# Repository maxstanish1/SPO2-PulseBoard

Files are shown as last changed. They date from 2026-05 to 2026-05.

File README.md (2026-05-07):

# SPO2-PulseBoard
A custom heart rate and SpO2 monitor built on an Arduino Uno R3 with a MAX30105 sensor and SSD1306 OLED display. Features a custom PCB, mode-switching buttons, and an alarm LED. Uses lightweight R-ratio SpO2 calculation and peak-detection heart rate — all tuned to run within the Arduino Uno's RAM limits.



# PulseBoard

A custom heart rate and SpO2 monitor built on an Arduino Uno R3 with a MAX30105 sensor and SSD1306 OLED display. Features a custom PCB, mode-switching buttons, and an alarm LED. Uses lightweight R-ratio SpO2 calculation and peak-detection heart rate — all tuned to run within the Arduino Uno's RAM limits.

---

## Hardware

| Component | Details |
|---|---|
| Microcontroller | Arduino Uno R3 |
| Sensor | MAX30105 optical heart rate / SpO2 |
| Display | SSD1306 128×32 OLED (I2C) |
| PCB | Custom — see `/hardware` for Gerber files |

### Pin Map

| Pin | Function |
|-----|---|
| D2 | Menu button — cycles between Heart Rate and SpO2 mode |
| D3 | Up button — reserved for future use |
| D4 | Down button — reserved for future use |
| D12 | Alarm LED — flashes when no finger is on the sensor |
| SDA / SCL | Shared I2C bus → MAX30105 + SSD1306 |

### Button Circuit
All three buttons are active-low, held HIGH by 1kΩ pull-up resistors (R1, R2, R3) with 100nF decoupling capacitors for hardware debounce. The alarm LED is driven through a 1kΩ current-limiting resistor (R4).

---

## Features

- **Heart Rate (BPM)** — peak detection on a rolling IR signal window with a 4-beat rolling average
- **SpO2 (%)** — R-ratio method with a quadratic calibration formula for accurate readings in the healthy range
- **Mode switching** — press D2 to toggle between Heart Rate and SpO2 mode; a splash screen confirms the switch
- **Alarm LED** — flashes at 1Hz on D12 when no finger is detected, turns off immediately when a finger is placed
- **Stable display** — 500ms refresh throttle prevents flicker; readings are held back for the first few seconds until the signal stabilizes

---

## How It Works

### Finger Detection
The sketch polls the MAX30105 every loop. An IR value above 50,000 indicates a finger is present (tissue absorbs the light). Below that threshold, the sensor is reading open air. All HR and SpO2 state resets on each new finger placement.

### Heart Rate Detection
A 10-sample rolling window tracks the IR signal's min, max, and range. Beat detection fires when the signal crosses 50% of the range, subject to these parameters:

| Parameter | Value |
|---|---|
| Threshold | 50% of signal range |
| Minimum signal range | 400 |
| Minimum time between beats | 400ms |
| First beat | Always skipped (timing invalid) |
| Valid BPM range | 50 – 120 |
| Rolling average | 4 beats |
| Avg display delay | 8 seconds |

### SpO2 Calculation
AC (peak-to-peak) and DC (midpoint) values are computed for both the Red and IR channels from the same 10-sample window. The R-ratio is calculated as:

```
R = (redAC / redDC) / (irAC / irDC)
```

R is then passed through a quadratic calibration formula fitted to empirical blood oxygen absorption data:

```
SpO2 = -45.060 × R² + 30.354 × R + 94.845
```

The result is clamped between 70–100% and smoothed with a 9-reading rolling average. Readings are displayed after 5 seconds.

> **Note:** This formula is accurate in the healthy range (95–100%). Readings below ~90% should be treated as approximate — the sensor is not designed for clinical low-SpO2 accuracy.

---

## Libraries Required

Install these through the Arduino IDE Library Manager before compiling:

- [Adafruit SSD1306](https://github.com/adafruit/Adafruit_SSD1306)
- [Adafruit GFX](https://github.com/adafruit/Adafruit-GFX-Library)
- [SparkFun MAX3010x](https://github.com/sparkfun/SparkFun_MAX3010x_Sensor_Library) — provides `MAX30105.h`

> **Note:** This project does NOT use `spo2_algorithm.h`. That library was tested but exceeded the Uno's available RAM. SpO2 logic here is a custom lightweight implementation.

---

## Usage

1. Wire up the hardware according to the pin map above or use the custom PCB
2. Install the required libraries
3. Upload `heart_monitor.ino` to your Arduino Uno R3
4. Place your finger **lightly** on the sensor — pressing too hard flattens the pulse waveform and stops beat detection
5. Press **D2** to switch between Heart Rate and SpO2 mode
6. Wait 8 seconds for a stable heart rate average, or 5 seconds for an SpO2 reading

---

## Known Limitations

- **Finger pressure is critical** — too much pressure drops the signal range below 400 and halts detection
- **INT pin unused** — the MAX30105 interrupt pin is wired on the PCB but unconnected in firmware. Currently the sketch polls the sensor every loop. Future enhancement: wire INT to D7 for event-driven reads
- **SpO2 accuracy** — reliable in the 95–100% range; not suitable for clinical use
- **BPM range** — capped at 50–120 BPM; athletes with resting HR below 50 will see no reading

---

## Project Structure

```
PulseBoard/
├── firmware/
│   └── heart_monitor.ino
├── hardware/
│   └── (Gerber files, schematic)
└── README.md
```

---

## License

MIT

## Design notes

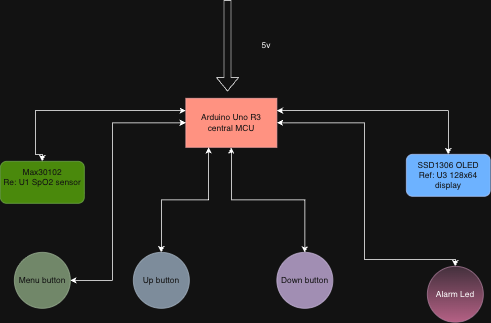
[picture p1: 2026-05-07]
Untitled Diagram.drawio (1).png

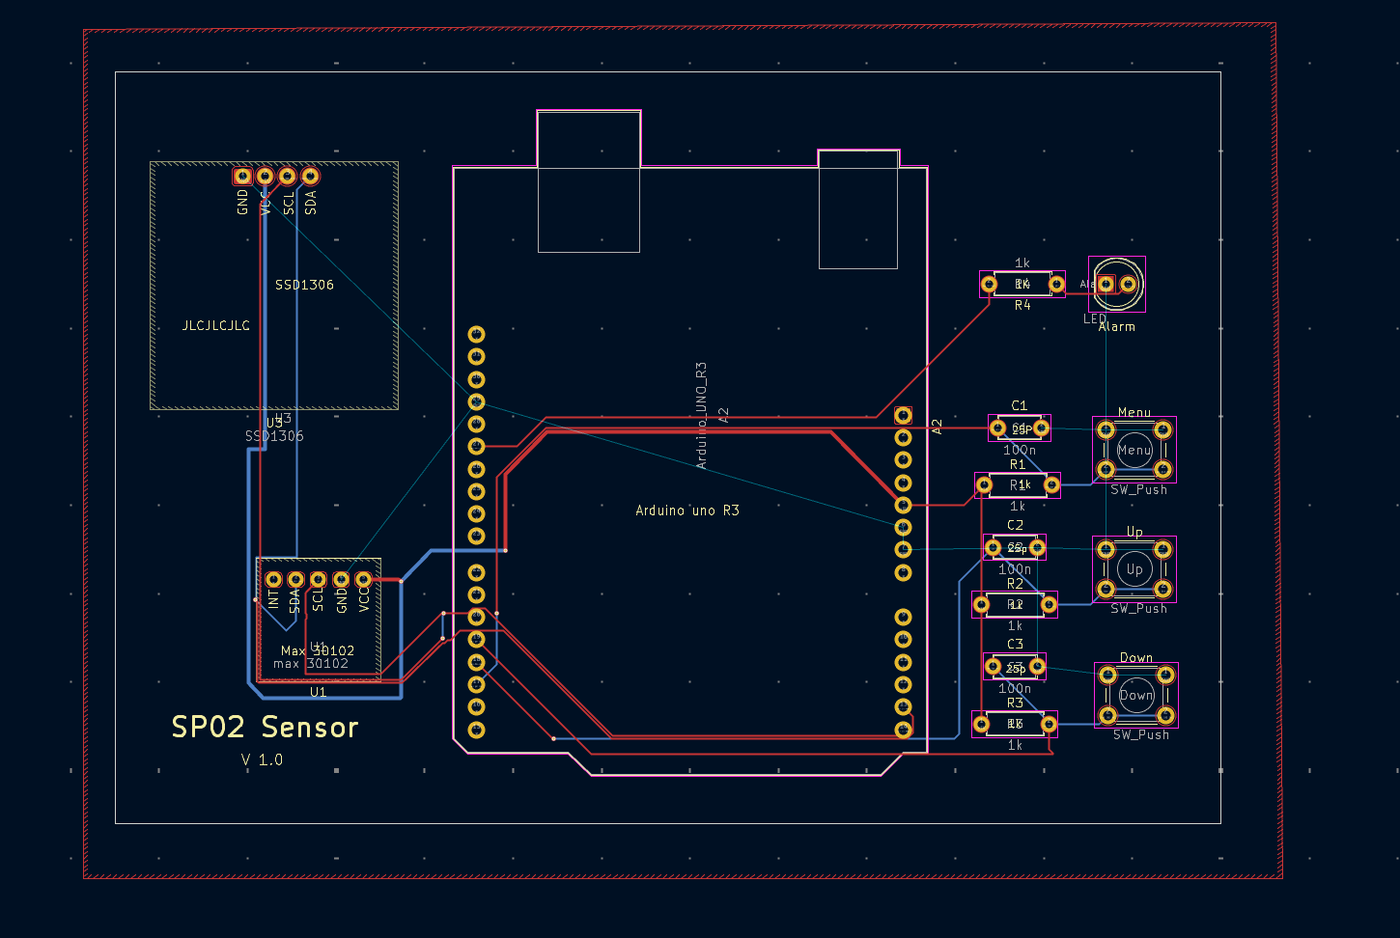
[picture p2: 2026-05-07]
SPO2 KiCAD layout.png

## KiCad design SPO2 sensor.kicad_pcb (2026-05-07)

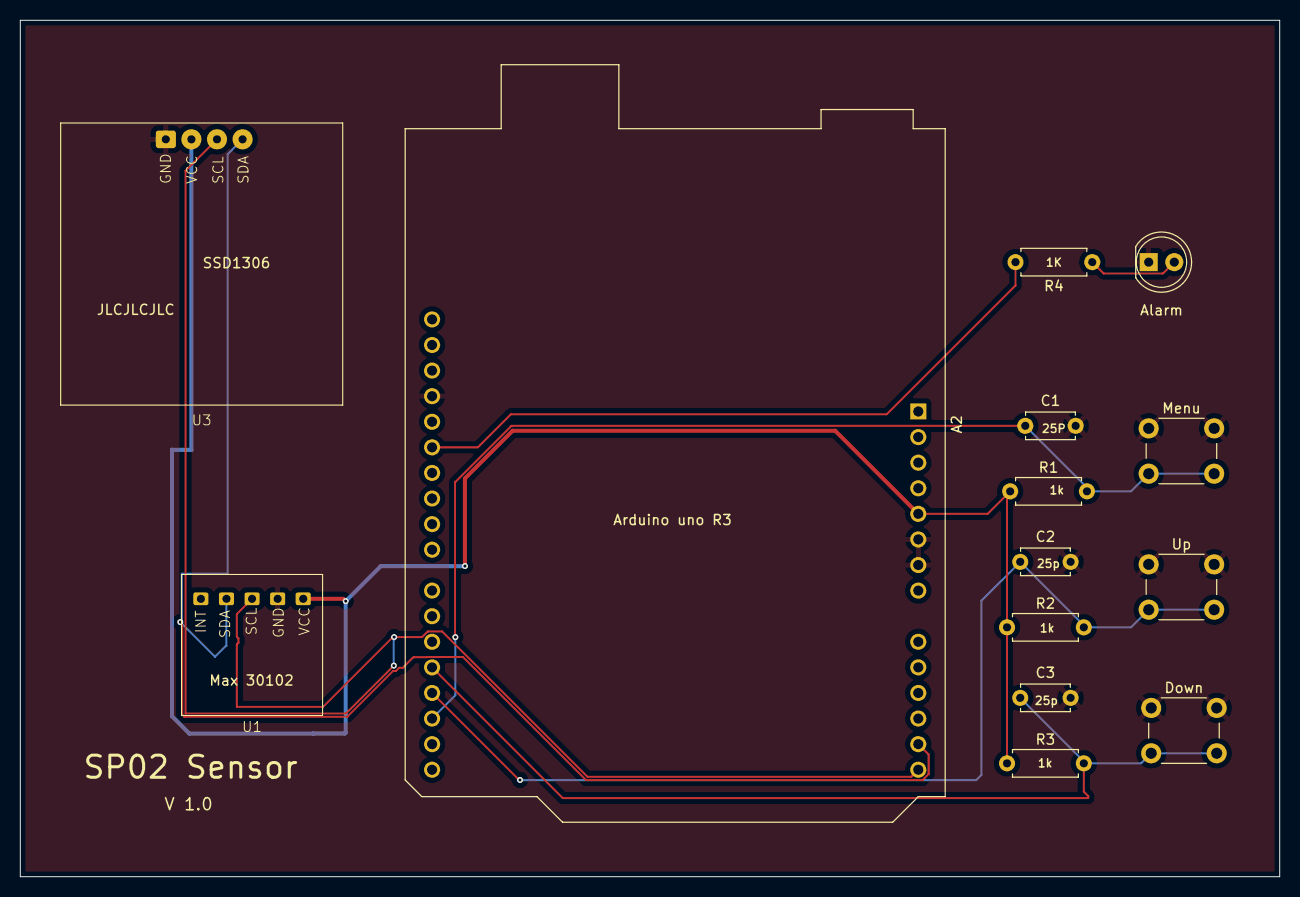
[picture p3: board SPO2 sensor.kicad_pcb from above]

Board: 2 copper layers, 125.0 x 85.0 mm, 14 parts (0 on the bottom side), 9 nets.

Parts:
A2: Arduino_UNO_R3
Alarm: LED; LED_D5.0mm
C1, C2, C3: 100n; C_Disc_D4.7mm_W2.5mm_P5.00mm
Down: SW_Push; SW_PUSH_6mm
Menu: SW_Push; SW_PUSH_6mm
R1, R2, R3, R4: 1k; R_Axial_DIN0207_L6.3mm_D2.5mm_P7.62mm_Horizontal
U1: max 30102; spo2 max30102
U3: SSD1306
Up: SW_Push; SW_PUSH_6mm

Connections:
+5V: A2.5 (+5V), R1.1, R2.1, R3.1, U1.5 (VCC), U3.2 (SCL)
GND: A2.6 (GND), A2.7 (GND), A2.29 (GND), Alarm.1 (K), C1.2, C2.2, C3.2, Down.1, Menu.1, U1.4 (GND), U3.1 (Vcc), Up.1
unnamed: A2.17 (D2), C1.1, Menu.2, R1.2
unnamed: A2.18 (D3), C2.1, R2.2, Up.2
unnamed: A2.19 (D4), C3.1, Down.2, R3.2
unnamed: A2.27 (D12), R4.2
unnamed: Alarm.2 (A), R4.1
unnamed: A2.14 (SCL/A5), U1.3 (SCL), U3.3 (SDA)
unnamed: A2.13 (SDA/A4), U1.2 (SDA), U3.4 (GND)

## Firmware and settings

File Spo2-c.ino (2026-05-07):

/*
 * Heart Rate & SpO2 Monitor
 * Hardware: Elegoo Uno R3 + MAX30105 + SSD1306 OLED
 * 
 * Pin assignments (from PCB schematic):
 *   D2  → Menu button  (cycles between HR and SpO2 mode)
 *   D3  → Up button    (reserved / future use)
 *   D4  → Down button  (reserved / future use)
 *   D12 → Alarm LED    (flashes when no finger on sensor)
 *   SDA/SCL → MAX30105 + SSD1306 on I2C bus
 *
 * Modes:
 *   MODE 0 = Heart Rate (BPM)
 *   MODE 1 = Blood Oxygen (SpO2 %)
 *
 * Button D2 cycles between modes.
 * LED on D12 flashes at 1Hz when no finger is detected, stays OFF when finger is on.
 */

#include <Wire.h>
#include <Adafruit_GFX.h>
#include <Adafruit_SSD1306.h>
#include "MAX30105.h"

// ─── Display ──────────────────────────────────────────────────────────────────
#define SCREEN_WIDTH    128
#define SCREEN_HEIGHT    32
#define OLED_RESET       -1
#define SCREEN_ADDRESS 0x3C
Adafruit_SSD1306 display(SCREEN_WIDTH, SCREEN_HEIGHT, &Wire, OLED_RESET);

// ─── Sensor ───────────────────────────────────────────────────────────────────
MAX30105 particleSensor;

// ─── Pin definitions (from Gerber schematic) ──────────────────────────────────
#define PIN_BTN_MENU  2    // Menu button  → cycles mode
#define PIN_BTN_UP    3    // Up button    → reserved
#define PIN_BTN_DOWN  4    // Down button  → reserved
#define PIN_ALARM_LED 12   // Alarm LED    → flashes when no finger

// ─── Mode ─────────────────────────────────────────────────────────────────────
#define MODE_HR   0
#define MODE_SPO2 1
int currentMode = MODE_HR;

// ─── Button debounce ──────────────────────────────────────────────────────────
bool     lastMenuState     = HIGH;
unsigned long lastMenuTime = 0;
#define DEBOUNCE_MS 50

// ─── LED flash state ──────────────────────────────────────────────────────────
unsigned long lastLedToggle = 0;
bool          ledState       = false;
#define LED_FLASH_INTERVAL 500

// ─── Heart rate detection ─────────────────────────────────────────────────────
const byte RATE_SIZE = 4;
byte       rates[RATE_SIZE];
byte       rateSpot        = 0;
long       lastBeat        = 0;
float      beatsPerMinute  = 0;
int        beatAvg         = 0;
int        displayBPM      = 0;
bool       beatDetected    = false;
bool       firstBeatSkipped = false;

// ─── IR signal buffers ────────────────────────────────────────────────────────
long irValueBuffer[10];
byte bufferIndex = 0;
long irMin = 999999;
long irMax = 0;

// ─── SpO2 calculation buffers ─────────────────────────────────────────────────
const byte SPO2_BUF_SIZE = 9;
long  redBuffer[10];
long  irBuffer_spo2[10];
byte  spo2BufIndex   = 0;
int   displaySpO2    = 0;
float spo2Readings[SPO2_BUF_SIZE];
byte  spo2ReadIndex  = 0;
byte  spo2Count      = 0;

// ─── Finger detection state ───────────────────────────────────────────────────
bool          fingerCurrentlyOn  = false;
unsigned long fingerPlacedTime   = 0;

// ─── Display refresh throttle ─────────────────────────────────────────────────
unsigned long lastDisplayUpdate = 0;
#define DISPLAY_REFRESH_MS 500


void setup() {
  Serial.begin(9600);
  delay(500);
  Serial.println("=== Heart Monitor Starting ===");

  pinMode(PIN_BTN_MENU, INPUT);
  pinMode(PIN_BTN_UP,   INPUT);
  pinMode(PIN_BTN_DOWN, INPUT);

  pinMode(PIN_ALARM_LED, OUTPUT);
  digitalWrite(PIN_ALARM_LED, LOW);

  if (!display.begin(SSD1306_SWITCHCAPVCC, SCREEN_ADDRESS)) {
    Serial.println("ERROR: Display failed!");
    for (;;);
  }
  Serial.println("Display OK");

  if (!particleSensor.begin(Wire, I2C_SPEED_FAST)) {
    Serial.println("ERROR: Sensor failed!");
    while (1);
  }
  Serial.println("Sensor OK");

  particleSensor.setup();
  particleSensor.setPulseAmplitudeRed(0x3F);
  particleSensor.setPulseAmplitudeIR(0x3F);

  for (int i = 0; i < 10;           i++) { irValueBuffer[i] = 0; redBuffer[i] = 0; irBuffer_spo2[i] = 0; }
  for (int i = 0; i < RATE_SIZE;    i++)   rates[i] = 0;
  for (int i = 0; i < SPO2_BUF_SIZE; i++) spo2Readings[i] = 0;

  Serial.println("=== Ready — press finger LIGHTLY ===");
  showModeSplash();
}


void loop() {
  handleMenuButton();

  long irValue  = particleSensor.getIR();
  long redValue = particleSensor.getRed();

  if (irValue > 50000 && !fingerCurrentlyOn) {
    fingerCurrentlyOn = true;
    fingerPlacedTime  = millis();
    lastBeat          = millis();

    beatAvg = 0; rateSpot = 0; displayBPM = 0;
    beatDetected = false; firstBeatSkipped = false;
    for (int i = 0; i < RATE_SIZE; i++) rates[i] = 0;

    displaySpO2 = 0; spo2ReadIndex = 0; spo2Count = 0;
    for (int i = 0; i < SPO2_BUF_SIZE; i++) spo2Readings[i] = 0;

    digitalWrite(PIN_ALARM_LED, LOW);
    ledState = false;
    Serial.println(">>> Finger placed");

  } else if (irValue < 50000 && fingerCurrentlyOn) {
    fingerCurrentlyOn = false;
    Serial.println(">>> Finger removed");
  }

  if (!fingerCurrentlyOn) {
    if (millis() - lastLedToggle >= LED_FLASH_INTERVAL) {
      lastLedToggle = millis();
      ledState = !ledState;
      digitalWrite(PIN_ALARM_LED, ledState ? HIGH : LOW);
    }
  }

  irValueBuffer[bufferIndex] = irValue;
  redBuffer[bufferIndex]     = redValue;
  irBuffer_spo2[bufferIndex] = irValue;
  bufferIndex = (bufferIndex + 1) % 10;

  irMin = 999999; irMax = 0;
  for (int i = 0; i < 10; i++) {
    if (irValueBuffer[i] < irMin) irMin = irValueBuffer[i];
    if (irValueBuffer[i] > irMax) irMax = irValueBuffer[i];
  }

  long range     = irMax - irMin;
  long threshold = irMin + (range * 0.50);

  if (fingerCurrentlyOn && range > 400) {
    if (irValue > threshold && !beatDetected && (millis() - lastBeat > 400)) {
      beatDetected = true;
      long delta = millis() - lastBeat;
      lastBeat   = millis();

      if (!firstBeatSkipped) {
        firstBeatSkipped = true;
        Serial.println("FIRST BEAT — skipped (calibrating)");
      } else {
        beatsPerMinute = 60000.0 / delta;
        if (beatsPerMinute >= 50 && beatsPerMinute <= 120) {
          displayBPM = (int)beatsPerMinute;
          rates[rateSpot++] = (byte)beatsPerMinute;
          rateSpot %= RATE_SIZE;
          int validCount = 0; beatAvg = 0;
          for (byte x = 0; x < RATE_SIZE; x++) {
            if (rates[x] > 0) { beatAvg += rates[x]; validCount++; }
          }
          if (validCount > 0) beatAvg /= validCount;
          Serial.print("BEAT! BPM="); Serial.print(beatsPerMinute, 1);
          Serial.print(" Avg="); Serial.println(beatAvg);
        }
      }
    }
    if (irValue < (threshold - (range * 0.15))) beatDetected = false;
  }

  if (fingerCurrentlyOn) {
    long redWinMin = 999999, redWinMax = 0;
    long irWinMin  = 999999, irWinMax  = 0;
    for (int i = 0; i < 10; i++) {
      if (redBuffer[i] > 0) {
        if (redBuffer[i] < redWinMin) redWinMin = redBuffer[i];
        if (redBuffer[i] > redWinMax) redWinMax = redBuffer[i];
      }
      if (irBuffer_spo2[i] > 0) {
        if (irBuffer_spo2[i] < irWinMin) irWinMin = irBuffer_spo2[i];
        if (irBuffer_spo2[i] > irWinMax) irWinMax = irBuffer_spo2[i];
      }
    }

    float redAC = redWinMax - redWinMin;
    float irAC  = irWinMax  - irWinMin;
    float redDC = (redWinMax + redWinMin) / 2.0;
    float irDC  = (irWinMax  + irWinMin)  / 2.0;

    if (redDC > 0 && irDC > 0 && irAC > 0 && redAC > 0) {
      float R = (redAC / redDC) / (irAC / irDC);
      float spo2Val = -45.060 * R * R + 30.354 * R + 94.845;
      if (spo2Val > 100.0) spo2Val = 100.0;
      if (spo2Val < 70.0)  spo2Val = 70.0;

      spo2Readings[spo2ReadIndex] = spo2Val;
      spo2ReadIndex = (spo2ReadIndex + 1) % SPO2_BUF_SIZE;
      if (spo2Count < SPO2_BUF_SIZE) spo2Count++;

      float sum = 0;
      for (int i = 0; i < spo2Count; i++) sum += spo2Readings[i];
      displaySpO2 = (int)(sum / spo2Count);
    }
  }

  if (millis() - lastDisplayUpdate >= DISPLAY_REFRESH_MS) {
    lastDisplayUpdate = millis();
    updateDisplay(irValue);
  }

  delay(20);
}


void handleMenuButton() {
  bool menuState = digitalRead(PIN_BTN_MENU);
  if (menuState == LOW && lastMenuState == HIGH &&
      (millis() - lastMenuTime > DEBOUNCE_MS)) {
    lastMenuTime = millis();
    currentMode = (currentMode == MODE_HR) ? MODE_SPO2 : MODE_HR;
    Serial.print("Mode changed → ");
    Serial.println(currentMode == MODE_HR ? "HEART RATE" : "SpO2");
    showModeSplash();
  }
  lastMenuState = menuState;
}


void showModeSplash() {
  display.clearDisplay();
  display.setTextColor(WHITE);
  display.setTextSize(1);
  display.setCursor(20, 12);
  display.print(currentMode == MODE_HR ? ">> Heart Rate Mode" : ">> SpO2 Mode");
  display.display();
  delay(800);
}


void updateDisplay(long irValue) {
  display.clearDisplay();
  display.setTextColor(WHITE);

  if (irValue > 50000) {
    unsigned long timeOn = millis() - fingerPlacedTime;

    if (currentMode == MODE_HR) {
      if (millis() - lastBeat < 200) {
        display.setTextSize(2);
        display.setCursor(0, 8);
        display.print("<3");
      }
      display.setTextSize(1);
      display.setCursor(35, 0);  display.print("Live:");
      display.setCursor(70, 0);
      if (displayBPM > 0) display.print(displayBPM);
      else                display.print("--");
      display.setCursor(35, 16); display.print("Avg :");
      display.setTextSize(2);
      display.setCursor(70, 12);
      if (timeOn >= 8000 && beatAvg > 0) display.print(beatAvg);
      else                                display.print("--");

    } else {
      display.setTextSize(1);
      display.setCursor(0, 0);   display.print("SpO2");
      display.setTextSize(2);
      display.setCursor(0, 14);
      if (timeOn >= 5000 && displaySpO2 > 0) {
        display.print(displaySpO2);
        display.setTextSize(1); display.print("%");
      } else {
        display.print("--");
      }
      display.setTextSize(1);
      display.setCursor(80, 14); display.print("O2 Sat");
    }

  } else {
    display.setTextSize(1);
    display.setCursor(15, 4);  display.print("Place Finger");
    display.setCursor(15, 20);
    display.print(currentMode == MODE_HR ? "[Heart Rate]" : "[SpO2]");
  }

  display.display();
}

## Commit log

2026-05-07 Create Gerber files
2026-05-07 Update Gerber files
2026-05-07 SPO2 gerber files and board layout PNG
    [SPO2 sensor.kicad_pcb]
2026-05-07 Update README to replace 'Elegoo Uno R3' with 'Arduino Uno R3'
2026-05-07 SPO2 block diagram
    PulseBoard accepts a 5V or 9V input, which is passed to the MAX30105 sensor and OLED display at 5V. The three tactile buttons and alarm LED also run on 5V — each button is paired with a 1kΩ pull-up r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
2026-05-07 Code used for the Arduino
